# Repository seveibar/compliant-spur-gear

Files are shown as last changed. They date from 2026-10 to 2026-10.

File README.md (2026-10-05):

# compliant-spur-gear

A parametric zero-backlash spur gear in OpenSCAD. Instead of a split gear held together by springs, every tooth has spring walls built in.

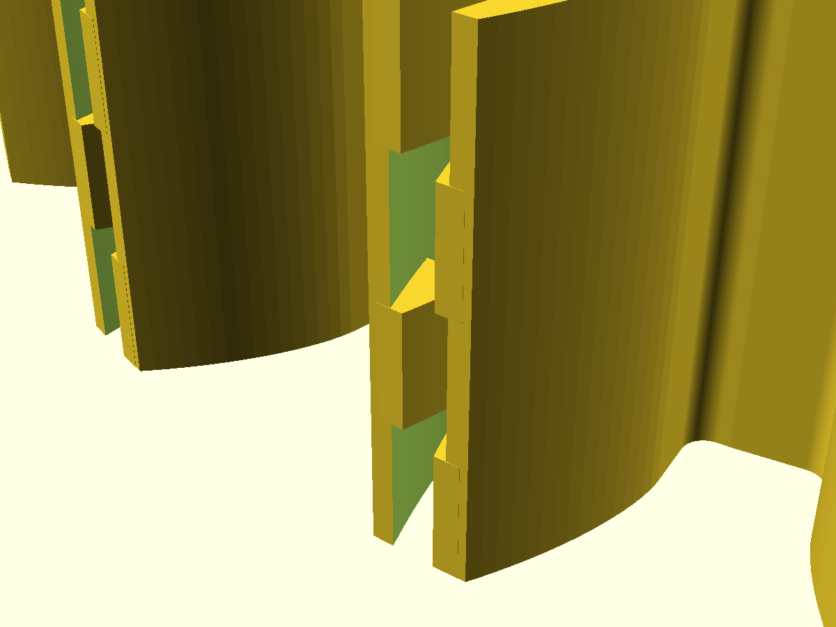
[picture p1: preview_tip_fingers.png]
Interleaved finger cap at the tooth tips


## How it works

- Each tooth is hollow. Its two flanks are thin cantilever walls rooted in the rim, and both run the full face width.
- The tooth is cut 0.10 mm oversize per flank. When it meshes at the nominal center distance, the mating gear pushes both walls toward the tooth center, which removes backlash.
- The tip is closed by interleaved fingers. Along Z the cap is split into layers, and in each layer one wall sends a finger across the slot.
- When the walls are pushed in, the fingers slide past each other. There is no separate stop: a wall stops when its finger reaches the inside of the opposite wall.

```
developed section through the cap (looking radially):

  z=F  |R wall|<==== R finger ====|  gap  |L wall|
       |R wall|  gap  |==== L finger ====>|L wall|
       |R wall|<==== R finger ====|  gap  |L wall|
  z=0  |R wall|  gap  |==== L finger ====>|L wall|
```

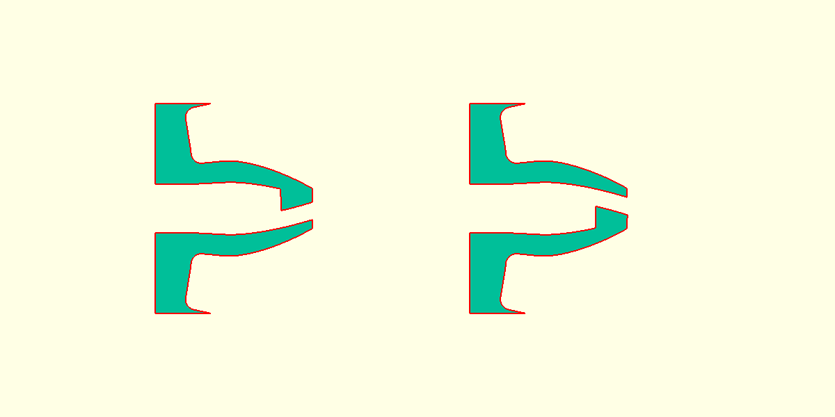
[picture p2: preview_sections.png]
Cross-sections through finger layers 1 and 2


## v2: print-friendly finger cap

`compliant_gear_v2.scad` has the same mechanism, but the fingers are 45° wedges instead of flat layers. When the gear prints flat, each v1 finger has a 90° overhang underneath. In v2 every downward-facing surface of the cap is at 45° (set by `overhang_angle`), so it prints without supports, and there's no thin layer gap to keep open.

In a section through the cap, the wedges form two interleaved rows of triangles, one row rooted in each wall. The tips still stop `cap_clearance` short of the opposite wall. The zig-zag period is chosen so the sloped faces have at least that much clearance (default: 4 L + 4 R wedges, 3.0 mm period).

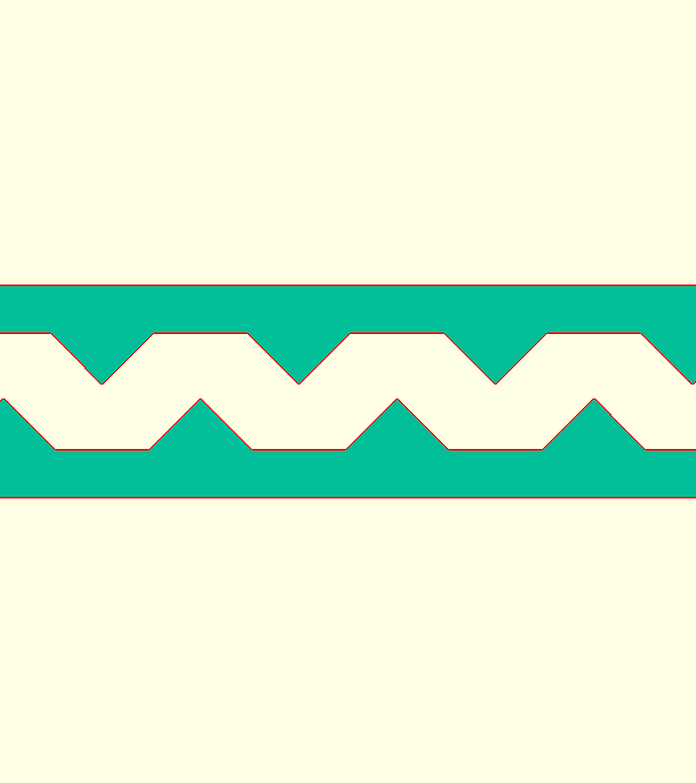
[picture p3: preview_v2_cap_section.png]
v2 section through the cap


## Files

| File | What it is |
|---|---|
| `compliant_gear.scad` | Parametric model (gear, mating pinion, assembly, sections) |
| `compliant_gear.stl` | Exported gear (default parameters) |
| `compliant_gear_v2.scad` | v2 model with 45° wedge fingers |
| `compliant_gear_v2.stl` | Exported v2 gear |
| `compliant_gear_v2.step` | v2 as an exact B-rep (STEP), rebuilt in build123d |
| `drawing/v2-views/` | v2 standard views sheet (top / front / right / iso) and its scripts |
| `pinion.stl` | Plain 16-tooth mating pinion |
| `test_stand.scad` / `test_stand.stl` | Two-pillar stand for meshing two 20T gears to test backlash |
| `drawing/compliant-gear-drawing.html` | Engineering drawing sheet (open in a browser) |
| `drawing/gen.py` | Generates the drawing from the same involute math |

## Defaults

Module 3, 20 teeth, 20° pressure angle, 12 mm face width, 8 mm bore. Mates with a 16-tooth pinion at 54.000 mm center distance.

| Parameter | Default | Meaning |
|---|---|---|
| `preload` | 0.10 | Extra flank thickness per side at the pitch circle |
| `hollow_frac` | 0.55 | Slot width as a fraction of tooth width |
| `slot_depth` | 2.0 | How far the slot goes below the root circle |
| `cap_height` | 1.8 | Radial height of the finger cap |
| `cap_layers` | 4 | Number of interleaved finger layers |
| `cap_clearance` | 1.0 | Gap from a finger to the opposite wall, which sets the closing travel |
| `layer_gap` | 0.3 | Z clearance between finger layers |

A rough cantilever estimate for rigid resin (E ≈ 3.5 GPa) is about 75 N/mm per wall. That gives about 7.5 N of preload at mesh, and the fingers make contact after about 0.28 mm of wall travel at the pitch circle. These are first-order numbers, so test before relying on them.

## Building

```sh
openscad -o compliant_gear.stl -D 'show="gear"'   compliant_gear.scad
openscad -o pinion.stl         -D 'show="pinion"' compliant_gear.scad
openscad -o compliant_gear_v2.stl -D 'show="gear"' compliant_gear_v2.scad
python3 drawing/gen.py   # regenerate the drawing
```

`show` also accepts `assembly` and `tooth_sections`.

## Backlash test stand

`test_stand.scad` is a base plate with two pillars for meshing two of the 20-tooth gears. Each pillar has a Ø16 shoulder that the gear's hub sits on, 2 mm above the plate, so the teeth and spring walls never touch the floor. Above the shoulder is a Ø7.70 pin, which leaves 0.15 mm of radial clearance in the Ø8 bore.

The gears preload each other, which pushes them apart against the outer sides of their pins. To compensate, the pins are 2 × 0.15 mm closer than the nominal 60.00 mm center distance, so the gears mesh at exactly 60.00 mm. Set `extra_center_distance` above 0 to open the mesh and make backlash appear.

## Printing

v1's defaults (0.30 mm between layers, about 0.27 mm finger tips) are meant for SLA, SLS or MJF. For FDM, use v2: its cap has no unsupported overhangs. The wedge tips are still fine features, so a larger module helps.

## License

MIT

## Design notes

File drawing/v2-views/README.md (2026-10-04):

# v2 standard views

`compliant-gear-v2-views.html` is a third-angle drawing sheet with top, front, right and isometric views, plus an isometric detail of one tooth.

The views are hidden-line projections (OpenCascade HLR) of an exact B-rep rebuild of `compliant_gear_v2.scad`. The rebuild's volume matches the OpenSCAD STL to 0.04%.

```sh
pip install build123d
python model_v2.py   # builds the B-rep, writes compliant_gear_v2.step
python views.py      # projects the views -> views.json (~1 min)
python sheet.py      # composes the sheet -> compliant-gear-v2-views.html
```

`model_v2.py` copies its parameters from the `.scad` file by hand, so keep the two in sync.

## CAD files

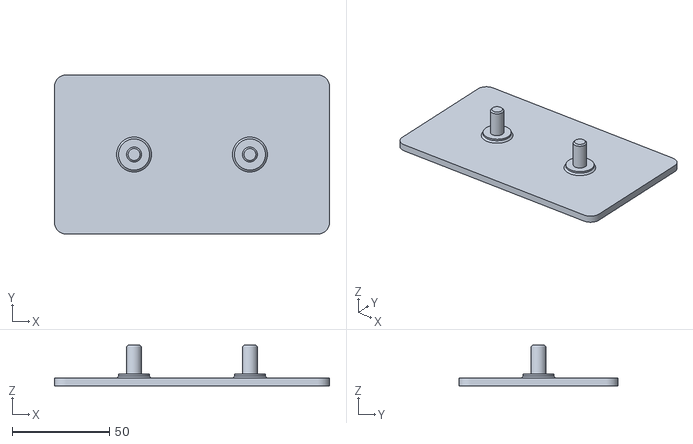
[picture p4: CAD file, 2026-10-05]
test_stand.stl
141.7 x 82.0 x 21.0

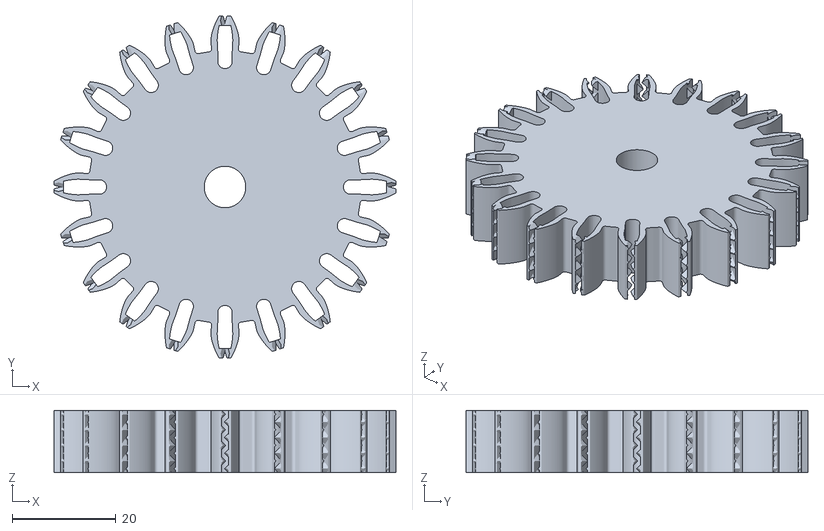
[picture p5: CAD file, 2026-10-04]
compliant_gear_v2.stl
66.0 x 66.0 x 12.0

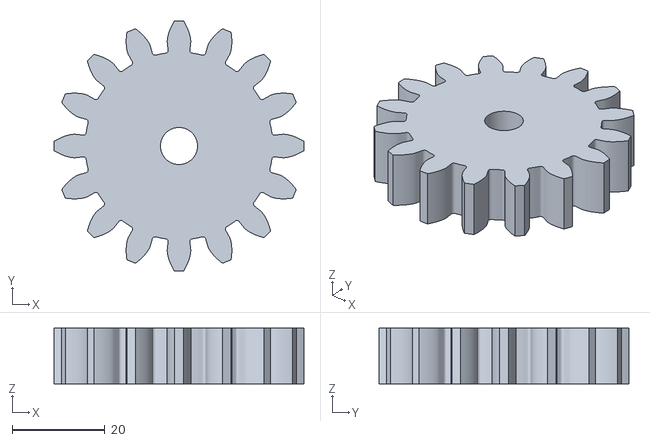
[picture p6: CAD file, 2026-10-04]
pinion.stl
54.0 x 54.0 x 12.0

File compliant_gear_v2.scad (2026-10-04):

// Zero-backlash compliant spur gear — v2 (print-friendly finger cap)
// -------------------------------------------------------------------
// Same mechanism as v1 (compliant_gear.scad): every tooth is hollow, its two
// flanks are full-width cantilever walls, the tooth is cut oversize by
// `preload` per flank, and the tip is closed by interleaved fingers that
// slide past each other until a finger reaches the opposite wall.
//
// v1 stacked flat finger layers, so the underside of every finger was a 90°
// overhang. In v2 each finger is a wedge whose faces are at
// `overhang_angle` from vertical, and the L and R wedges interleave as a
// zig-zag. Printed flat (Z up), every downward-facing surface of the cap is
// self-supporting.
//
// In a planar section through the cap (normal to the tooth axis) the L and
// R wedges form two interleaved rows of 45° triangles, one row rooted in
// each wall, with clearance on every face.
//
// Closing travel is still `cap_clearance`: tips reach the opposite wall
// before the sloped faces meet (the slope gap is >= cap_clearance).

/* [Gear] */
module_m       = 3;     // module [mm]
teeth          = 20;
face_width     = 12;    // [mm]
pressure_angle = 20;    // [deg]
bore_d         = 8;

/* [Compliance] */
preload        = 0.10;  // extra flank thickness at pitch circle, per side [mm]
hollow_frac    = 0.55;  // slot width as a fraction of tooth width
slot_depth     = 2.0;   // how far the slot goes below the root circle [mm]
cap_height     = 1.8;   // radial height of the finger cap, down from the tip [mm]
cap_clearance  = 1.0;   // finger tip to opposite wall at rest = closing travel [mm]
overhang_angle = 45;    // wedge face angle from vertical; 45 prints unsupported [deg]
root_fillet    = 0.6;

/* [Mating pinion (for assembly preview)] */
pinion_teeth   = 16;
show           = "assembly"; // [gear, pinion, assembly, tooth_sections, tooth_closeup]

$fn = 96;
STEPS = 24;

// ---------- involute math (radians) ----------
function deg(a) = a * 180 / PI;
function rad(a) = a * PI / 180;
function inv(a_rad) = tan(deg(a_rad)) - a_rad;

function rp(N)  = module_m * N / 2;
function rb(N)  = rp(N) * cos(pressure_angle);
function ra(N)  = rp(N) + module_m;
function rf(N)  = rp(N) - 1.25 * module_m;

// half angular tooth thickness at radius r [rad]
function psi(N, r, pl) =
    let(rr = max(r, rb(N)),
        a_r = acos(rb(N) / rr))
    PI / (2 * N) + pl / rp(N) + inv(rad(pressure_angle)) - inv(rad(a_r));

function polar(r, a_rad) = [r * cos(deg(a_rad)), r * sin(deg(a_rad))];

function radii(r0, r1) = [for (i = [0:STEPS]) r0 + (r1 - r0) * i / STEPS];

// slot half angle at radius r
function slot_a(N, r) = hollow_frac * psi(N, min(r, ra(N)), preload);
function slot_hw(N) = rf(N) * slot_a(N, rf(N));

// ---------- 2D primitives ----------
module tooth2d(N, pl) {
    r0 = rf(N) - 0.5;
    rs = radii(r0, ra(N));
    right = [for (r = rs) polar(r, -psi(N, r, pl))];
    left  = [for (i = [len(rs) - 1:-1:0]) polar(rs[i], psi(N, rs[i], pl))];
    polygon(concat(right, left));
}

module gear2d(N, pl) {
    offset(r = -root_fillet) offset(delta = root_fillet)
    union() {
        circle(r = rf(N));
        for (i = [0:N - 1]) rotate(i * 360 / N) tooth2d(N, pl);
    }
}

// slot (hollow) inside the tooth at angle 0, open at the tip
module slot2d(N) {
    rs = radii(rf(N), ra(N) + 1);
    hw = slot_hw(N);
    right = [for (r = rs) polar(r, -slot_a(N, r))];
    left  = [for (i = [len(rs) - 1:-1:0]) polar(rs[i], slot_a(N, rs[i]))];
    union() {
        polygon(concat(right, left));
        // extension into the rim for a longer, softer cantilever
        translate([rf(N) - slot_depth, -hw]) square([slot_depth + 0.05, 2 * hw]);
        translate([rf(N) - slot_depth, 0]) circle(r = hw, $fn = 32);
    }
}

// ---------- finger wedges ----------
function rcap(N) = ra(N) - cap_height;
// widest slot half width in the cap sets the zig-zag period
function s_max(N) = rcap(N) * slot_a(N, rcap(N));
// slope gap = P/2*tan + 2c - 2s >= c  =>  P >= 2(2s - c)/tan
function period_min(N) = 2 * (2 * s_max(N) - cap_clearance) / tan(overhang_angle);
function n_periods(N) = max(1, floor(face_width / period_min(N)));
function period(N) = face_width / n_periods(N);

// one wedge-shaped finger from wall `side` (+1 = L, CCW), apex at height z.
// In each radial slice it is a triangle in (tangential, z): apex at the tip,
// cap_clearance short of the other wall; base inside its own wall.
module wedge(N, side, z) {
    rs = radii(rcap(N), ra(N));
    n = len(rs);
    pts = [for (r = rs) let(
                aw = side * (slot_a(N, r) + 0.01),
                at = -side * (slot_a(N, r) - cap_clearance / r),
                h  = r * abs(aw - at) / tan(overhang_angle))
            each [[r * cos(deg(at)), r * sin(deg(at)), z],
                  [r * cos(deg(aw)), r * sin(deg(aw)), z - h],
                  [r * cos(deg(aw)), r * sin(deg(aw)), z + h]]];
    sides = [for (i = [0:n - 2]) let(a = 3 * i, b = 3 * i + 3)
                each [[a, b, b + 1], [a, b + 1, a + 1],
                      [a + 1, b + 1, b + 2], [a + 1, b + 2, a + 2],
                      [a + 2, b + 2, b], [a + 2, b, a]]];
    caps = [[0, 1, 2], [3 * n - 3, 3 * n - 1, 3 * n - 2]];
    polyhedron(points = pts, faces = concat(caps, sides), convexity = 4);
}

module fingers3d(N) {
    P = period(N);
    intersection() {
        union()
            for (k = [-1:n_periods(N)]) {
                wedge(N,  1, (k + 0.25) * P);
                wedge(N, -1, (k + 0.75) * P);
            }
        translate([0, 0, face_width / 2])
            cube([4 * ra(N), 4 * ra(N), face_width], center = true);
    }
}

echo(str("v2 finger period ", period(teeth), " mm, ", n_periods(teeth),
         " L + ", n_periods(teeth), " R wedges; slope gap at cap root ",
         period(teeth) / 2 * tan(overhang_angle) + 2 * cap_clearance - 2 * s_max(teeth), " mm"));

module compliant_gear(N = teeth) {
    F = face_width;
    union() {
        difference() {
            linear_extrude(F) gear2d(N, preload);
            translate([0, 0, -1]) cylinder(d = bore_d, h = F + 2);
            for (i = [0:N - 1]) rotate(i * 360 / N)
                translate([0, 0, -1]) linear_extrude(F + 2) slot2d(N);
        }
        for (i = [0:N - 1]) rotate(i * 360 / N) fingers3d(N);
    }
}

module pinion(N = pinion_teeth) {
    difference() {
        linear_extrude(face_width) gear2d(N, 0);
        translate([0, 0, -1]) cylinder(d = bore_d, h = face_width + 2);
    }
}

module assembly() {
    color("orange") compliant_gear();
    a = rp(teeth) + rp(pinion_teeth);   // nominal center distance
    color("steelblue", 0.85)
        translate([a, 0, 0]) rotate(180 + 180 / pinion_teeth) pinion();
}

// cross sections through an L-finger apex and an R-finger apex
module tooth_sections() {
    zs = [0.25 * period(teeth) + period(teeth), 0.75 * period(teeth) + period(teeth)];
    for (i = [0:1])
        translate([i * 18, 0, 0])
        translate([-rp(teeth), 0, 0])
        projection(cut = true) translate([0, 0, -zs[i]])
            intersection() {
                compliant_gear();
                translate([rp(teeth) - 6, -6, -1]) cube([12, 12, face_width + 2]);
            }
}

if (show == "gear")           compliant_gear();
else if (show == "pinion")    pinion();
else if (show == "assembly")  assembly();
else if (show == "tooth_sections") tooth_sections();
else if (show == "tooth_closeup")
    intersection() {
        compliant_gear();
        translate([rp(teeth) - 4, -5, -1]) cube([8, 10, face_width + 2]);
    }

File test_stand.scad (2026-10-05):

// Backlash test stand for two compliant_gear.scad (v1) gears
// ----------------------------------------------------------
// A base plate with two pillars. Each pillar is a wide shoulder that the
// gear's hub sits on (so the teeth and spring walls never touch the plate)
// and a pin that runs through the gear's bore with a small clearance.
//
// The two compliant gears preload each other, which pushes them apart, so
// each gear rides against the outer side of its pin. The pins are therefore
// placed 2 x pin_clearance closer than the nominal center distance: once the
// preload takes up the clearance, the gears mesh at exactly the nominal
// distance. Set `extra_center_distance` > 0 to open the mesh up and watch
// backlash appear.

/* [Gears being tested] */
module_m       = 3;
teeth          = 20;     // both gears
gear_bore_d    = 8;
gear_width     = 12;

/* [Pillars] */
pin_clearance  = 0.15;   // radial clearance between pin and bore [mm]
shoulder_d     = 16;     // must stay inside the slot bottoms (~Ø46)
shoulder_h     = 2.0;    // gap between gear and plate
pin_extra      = 3.0;    // pin length above the gear's top face
pin_chamfer    = 0.8;
extra_center_distance = 0;  // >0 opens the mesh to show backlash

/* [Base] */
plate_t        = 4;
plate_margin   = 8;      // beyond the gear tips
corner_r       = 6;

/* [Preview] */
show           = "stand"; // [stand, assembly]

$fn = 96;

use <compliant_gear.scad>   // modules only; used for the assembly preview

center_nominal = module_m * teeth;          // 2 x pitch radius
pin_spacing    = center_nominal - 2 * pin_clearance + extra_center_distance;
pin_d          = gear_bore_d - 2 * pin_clearance;
tip_r          = module_m * teeth / 2 + module_m;

module pillar() {
    // shoulder with a small fillet-like flare into the plate
    cylinder(d1 = shoulder_d + 2, d2 = shoulder_d, h = 1);
    cylinder(d = shoulder_d, h = shoulder_h);
    // pin, chamfered at the top for easy insertion
    pin_h = shoulder_h + gear_width + pin_extra;
    cylinder(d = pin_d, h = pin_h - pin_chamfer);
    translate([0, 0, pin_h - pin_chamfer])
        cylinder(d1 = pin_d, d2 = pin_d - 2 * pin_chamfer, h = pin_chamfer);
}

module plate() {
    L = pin_spacing + 2 * (tip_r + plate_margin);
    Wd = 2 * (tip_r + plate_margin);
    translate([-(tip_r + plate_margin), -Wd / 2, -plate_t])
        linear_extrude(plate_t)
            offset(r = corner_r) offset(delta = -corner_r) square([L, Wd]);
}

module stand() {
    plate();
    pillar();
    translate([pin_spacing, 0, 0]) pillar();
}

if (show == "stand") stand();
else if (show == "assembly") {
    color("gray") stand();
    // gears pushed apart by their preload: each against the outer side of its pin
    color("orange")
        translate([-pin_clearance, 0, shoulder_h]) compliant_gear();
    color("gold")
        translate([pin_spacing + pin_clearance, 0, shoulder_h])
            rotate(180 + 180 / teeth) compliant_gear();
}

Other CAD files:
compliant_gear.stl
compliant_gear.scad

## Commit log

2026-10-04 Compliant zero-backlash spur gear: OpenSCAD model, STLs, drawing
    [compliant_gear.scad, compliant_gear.stl, pinion.stl]
2026-10-04 Add v2: 45° wedge finger cap for support-free printing
    [compliant_gear_v2.scad, compliant_gear_v2.stl]
2026-10-05 Add two-pillar backlash test stand
    [test_stand.scad, test_stand.stl]
